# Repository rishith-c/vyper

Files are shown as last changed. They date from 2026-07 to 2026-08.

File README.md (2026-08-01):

# VYPER

A fully 3D-printed high-speed FPV quadcopter, generated from parametric CAD
and verified by an automated test suite. Inspired by the
[Peregreen V4](https://airshaper.com/cases/peregreen-v4-fastest-drone) — the
3D-printed quadcopter that set the Guinness record at 657.59 km/h.

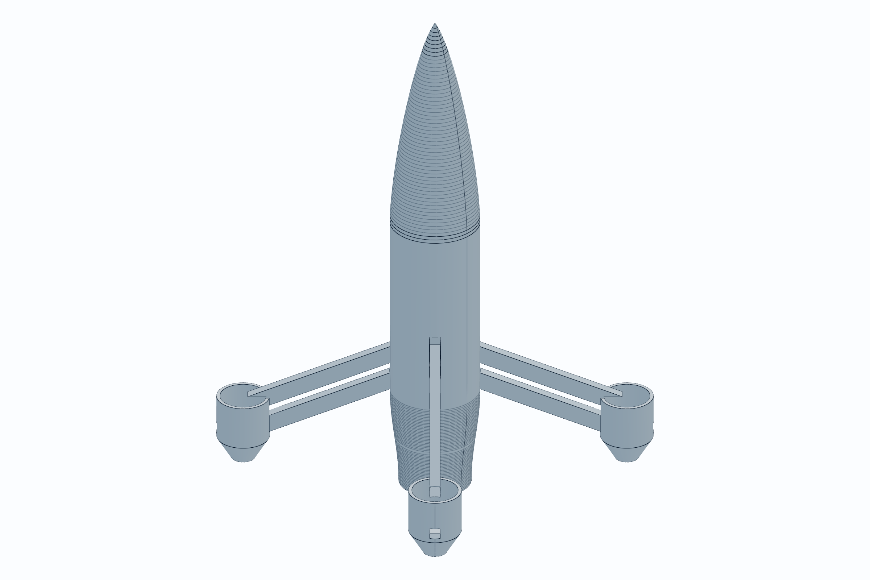
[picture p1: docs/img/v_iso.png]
assembly


| | |
|---|---|
| All-up weight | **567 g** |
| Thrust-to-weight | **8.1 : 1** |
| Drag area (CdA) | **39.4 cm²** — about half an open racer |
| Top speed | 139 km/h — **prop-pitch limited, not thrust limited** |
| Fuselage | 52 × 300 mm, fineness 5.77 |
| Bill of materials | **$142** |
| Automated checks | **30, all passing** |

---

## What's here

| | |
|---|---|
| [`vyper_shell.py`](vyper_shell.py) | The whole airframe in one CadQuery script — shell, arms, hub |
| [`test_vyper.py`](test_vyper.py) | 24 checks: fit, printing, tolerances, aero, mass |
| [`vyper_assembly.py`](vyper_assembly.py) | Assembly for review renders |
| [`firmware/`](firmware/) | Betaflight config + bench and pre-flight procedure |
| [`docs/BOM.md`](docs/BOM.md) | Every part, exact dimensions, links |
| [`pcb/`](pcb/) + [`docs/PCB_DESIGN.md`](docs/PCB_DESIGN.md) | Custom VYPER-F4 flight controller: KiCad 9 board, 15 interaction checks, dimensioned drawing |
| [`docs/TEST_REPORT.txt`](docs/TEST_REPORT.txt) | Latest full test output |
| [`stl/`](stl/) | Ready-to-print STLs |

```bash
pip install cadquery
python test_vyper.py      # verify
python vyper_shell.py     # build
```

---

## Design notes

**Von Kármán (LD-Haack) ogive nose** — the analytically minimum-drag nose for a
given length and base diameter, not a stylistic guess:

```
θ(x) = arccos(1 − 2x/L)
r(x) = (R/√π) · √(θ − sin(2θ)/2)
```

It meets the parallel body with zero slope discontinuity, so there's no
shoulder to trip the flow.

**Arms swept 22° aft, motors not canted.** On a tail-sitter the body axis *is*
the flight direction at speed, so a swept strut sees only the crossflow
component and its profile drag falls as cos²(sweep). The motor pads stay normal
to the body axis, so thrust is never canted — tilting the motors themselves
would cost 3.4 % of thrust at 15° and buy nothing here.

**Pusher, not tractor.** Motors bolt to the *aft* face of the arms with the
props behind them. A tractor gives the prop clean inflow, but its slipstream
then washes the entire fuselage above freestream velocity — and skin friction
scales with local dynamic pressure over what is nearly all the wetted area
there is. A pusher costs the prop some inflow quality and keeps the body in
clean air, which is the larger effect here. It is also why high-speed UAVs are
overwhelmingly pushers.

Consequence: motors are **inverted**, so all four directions reverse in
BLHeli/AM32 and `yaw_motors_reversed = ON`. Get that wrong and it flips on
yaw the instant you arm.

**Wire routing.** A 6 mm bore runs the length of each blade from the motor
pocket to the root, exiting inside the cavity — three 20 AWG leads (~4 mm
bundled) pull through by hand. Nothing flaps in a 139 km/h airstream. Bored
along the blade axis so it prints as a horizontal hole and bridges cleanly.

**Boat-tailed nacelles.** The pad's axis lies along the flow, so it behaves as
a nacelle and its drag is base drag off the flat aft end. Tapering to 45 %
radius removes most of that.

**Motor screws: M3×8 into a 4.0 mm pad** = 4.0 mm engagement in a 4.5 mm blind
thread. Washers under every head, because the pad is PETG and vibration embeds
a bare head over time. Threadlocker in the motor's aluminium thread, never on
the plastic.

---

## Three things the tests taught me

**Top speed was never thrust-limited.** 3.6 N of drag against 44 N available.
The ceiling is propeller pitch speed. Cutting drag doesn't raise it — it lowers
the power needed to hold it. That reframed the project: the fairing buys
efficiency and flight time, not speed.

**The tests caught what renders didn't.** A hub that exported as four
disconnected wedges. An arm frontal area computed against the wrong axis,
overstating its drag by 4.3×. A spline that self-intersected into a negative
volume. All of them looked fine on screen.

**Cheaper parts made it faster.** Re-specifying to $150 meant a smaller stack
and battery, which let the fuselage go 60 → 52 mm and lose 25 % of its frontal
area. The expensive ESC had been setting the diameter all along.

---

## Status and honesty

This is a **verified design, not a flown aircraft.** Everything here is checked
in software; none of it has been in the air. Treat the first build as a
prototype.

Known open items:
- **Motors are 84 % of remaining drag.** Fairing them is the biggest gain left.
- The fuselage is a sealed tube — there's a mandatory thermal bench check in
  [`firmware/PREFLIGHT.md`](firmware/PREFLIGHT.md) before you fly it.
- The $142 BOM covers the **aircraft only**. Radio, goggles and charger are a
  further $175–325 and you cannot fly without them.

## Safety

A 567 g aircraft at 139 km/h behind four unguarded props will cause serious
injury. Props off for all bench work. Fly only where regulations allow and
where nobody else is.

MIT licensed.

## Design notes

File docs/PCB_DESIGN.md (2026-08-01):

# VYPER-F4 — custom flight controller PCB

A placement-complete, dimensionally verified KiCad board for the VYPER
airframe. **15 automated interaction checks pass** (`pcb/test_vyper_f4.py`).

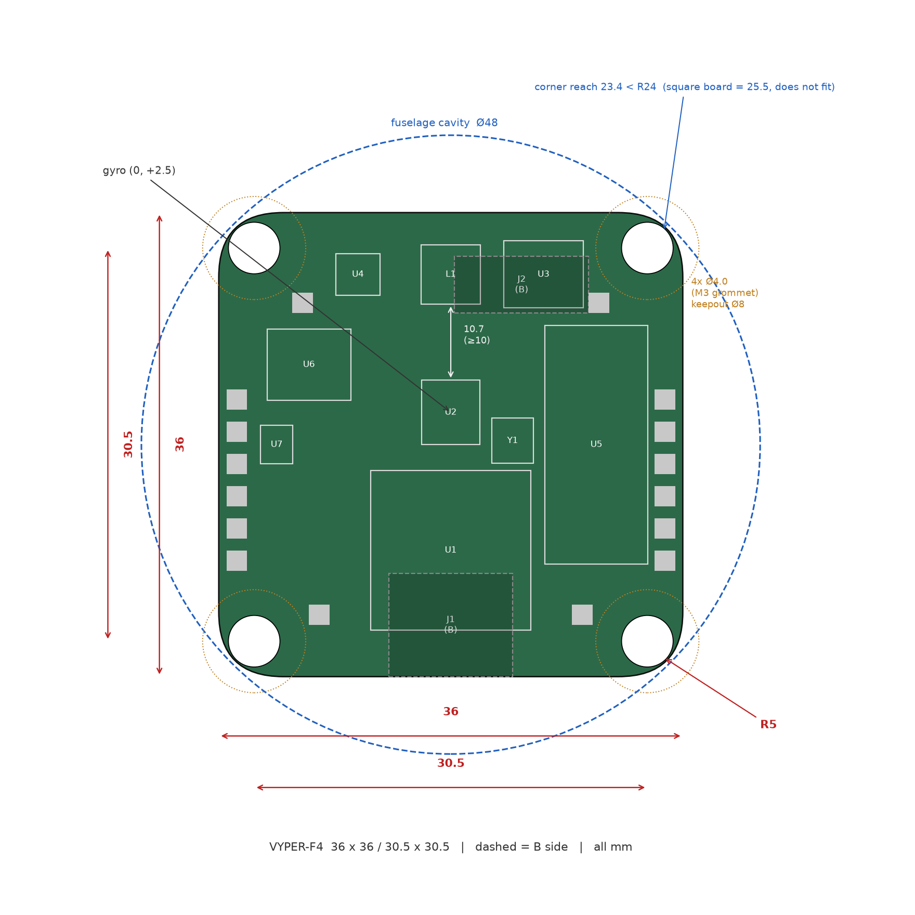
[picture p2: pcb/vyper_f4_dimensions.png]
dimensions


## What exists and what doesn't — read this first

| Done | Not done |
|---|---|
| Board outline, cut to the fuselage | Schematic capture (netlist) |
| 30.5×30.5 Φ4.0 grommet holes | Copper routing |
| Every major part placed, real package sizes | DRC against a fab profile |
| Courtyard / hole / pad interaction checks | Ordering files (gerbers/BOM/CPL) |
| KiCad 9 file that opens clean | |

That split is deliberate. Placement and dimensions are where an FC spin
dies silently — a board that doesn't fit its frame, holes that eat a
courtyard, a gyro next to an inductor. Routing is real work too, but it
fails *loudly* in DRC. Do it in the KiCad GUI or hand the placed board to an
AI router (below).

## The AI-tool landscape (researched July 2026)

| Tool | What it actually does | Use here? |
|---|---|---|
| [Quilter](https://www.quilter.ai/blog/the-2026-guide-to-autonomous-pcb-design-quilter-vs-deeppcb-vs-flux-ai) | Physics-driven cloud place-and-route of a *finished schematic*. Free tier. | **Yes** — best fit for routing this board once the netlist exists |
| [DeepPCB](https://www.protoflow.ai/compare/ai-pcb-autorouter-comparison) (InstaDeep) | RL-based cloud autorouter, free tier + pay-as-you-go | Yes, alternative router |
| [Flux.ai](https://www.protoflow.ai/compare/best-ai-pcb-design-software-2026) | Browser ECAD with AI copilot; explicitly *not* a full autorouter — route critical nets by hand, let it finish | Maybe, if you want schematic + layout in one tool |
| KiCad 9 + this repo | Deterministic generation from a Python layout file | What we did |

None of them design a *flight controller* for you: every tool above starts
from a schematic and placement intent. The intelligence in an FC layout is the
placement rules — which is exactly the part encoded and tested here.

## Design principles applied (and where each came from)

Sources: [Betaflight manufacturer design guidelines](https://betaflight.com/docs/development/manufacturer/manufacturer-design-guidelines),
[PCBSync drone PCB engineering guide](https://pcbsync.com/drone-pcb-design/),
[AllPCB flight-control layout guide](https://www.allpcb.com/allelectrohub/the-ultimate-guide-to-drone-flight-control-pcb-design-optimizing-for-performance-and-reliability).

1. **Gyro near the rotation centre, on the board axes.** ICM-42688-P at
   (0, +2.5) — 2.5 mm off centre, limit 4. A FWD axis mark is on the silk
   because a rotated gyro is a config error you chase for a week.
2. **Gyro ≥ 10 mm from anything that switches.** The buck inductor's field
   couples into the MEMS structure and reads as vibration that no filter
   fully removes. Measured on this board: **10.7 mm**, checked.
3. **Gyro-to-MCU SPI under 10 mm.** Courtyard gap here: ~0.8 mm.
4. **Soft mounting is a requirement, not a preference.** Hard-bolting the
   board flexes it and permanently shifts gyro bias — hence Φ4.0 holes for
   M3 grommets and a Φ8 keepout ring at each corner *on both faces*.
5. **Solid ground under the IMU; 4-layer stack** (sig / GND / PWR / sig)
   when routed — a continuous plane under high-frequency parts is the
   cheapest EMI fix there is.
6. **Power entry short and fat, cap at the connector.** Battery spikes on
   6S/4S kill FCs; the 470 µF low-ESR lives at the XT60, not on this board.
7. **USB and ESC socket on the bottom face** — the ESC harness plugs
   straight up from the stack below; USB faces the open tail of the
   fuselage. This is a case where the *airframe* dictated the PCB.

## Why the board is shaped by the fuselage

Two findings the checks enforce forever:

- **A square 36×36 board does not fit the VYPER fuselage.** Cavity radius is
  24 mm; a square board's half-diagonal is 25.46 mm. Corner radius ≥ 3.5 mm
  is *structural to the fit*; we use R5 → 23.38 mm reach, 0.6 mm air.
- **The classic corner motor-pad position is illegal on this board.** At
  (±13, ±13) all four pads sit inside the grommet keepouts — and M3
  additionally landed inside the blackbox-flash courtyard. The checks caught
  both; pads moved inboard.

## ESC: researched, deliberately not DIY'd

The same research pass covered ESC layout (gate-drive loops, shunt placement,
FET thermal spreading, bulk capacitance per phase). Conclusion: a 40 A 4-in-1
ESC is a **power-electronics project with a failure mode that takes the
battery with it**, on a board that costs $30 to buy with AM32 already on it.
Custom FC: sensible learning project. Custom ESC on a first spin: not.
Principles are in the sources above if you want them.

## Reproduce

```bash
cd pcb
python3 vyper_f4_gen.py                 # emit vyper_f4.kicad_pcb
python3 test_vyper_f4.py                # 15 interaction checks
../.venv/bin/python vyper_f4_drawing.py # dimensioned drawing
kicad-cli pcb render --side top --output top.png vyper_f4.kicad_pcb
```

The `.kicad_pcb` opens directly in KiCad 9 for schematic-linking and routing.

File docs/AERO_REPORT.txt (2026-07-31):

=== arms ===
two blades, 9 x 18 mm, 255 mm long, crossing at 77 deg
blade frontal silhouette      34.8 cm^2
  The blades make no useful lift and are not meant to. The whole
  point of this layout is that a 9 mm blade edge-on costs almost
  nothing, so the drag budget is body + motors and nothing else.

=== frame geometry ===
stretched X: 176 mm fore-aft / 140 mm lateral = 1.26:1
lateral spacing sits at the 127 mm prop minimum + 13 mm
exposed blade frontal area  34.8 cm^2

=== drag build-up ===
  fuselage           CdA =   3.02 cm^2  (   8 %)
  2 blades           CdA =   6.96 cm^2  (  18 %)
  4 motor bells      CdA =  28.67 cm^2  (  74 %)
  interference x1.15
  TOTAL              CdA =  44.45 cm^2
  open racer, same class   75.00 cm^2   -> 41 % less drag
  NOTE: the motors are now the single largest drag item. Fairing
  the airframe has made the bare bells the thing worth attacking.

=== top speed ===
prop 5x4.3 at ~30,303 rpm -> pitch speed  55.2 m/s
realistic max level speed       41.4 m/s =   149 km/h
drag there  4.66 N against  62.8 N available
  Thrust is NOT the limit -- prop pitch is. This is the single most
  important result here: the fairing does not raise the ceiling,
  it lowers what it costs to sit at the ceiling.

=== what the fairing actually buys ===
  at 30 m/s (108 km/h): drag 2.45 N vs 4.13 N open  ->  41 % less power to hold speed
  at 40 m/s (144 km/h): drag 4.36 N vs 7.35 N open  ->  41 % less power to hold speed

=== hover ===
disc area (4 props)           507 cm^2
disc loading                118.6 N/m^2
induced velocity              7.0 m/s
ideal hover power              42 W  (x ~1.9 for real figure of merit -> 79 W)
blade area inside the discs    42 cm^2 =  8.2 % of disc area  (measured)
estimated hover download    0.5 % of thrust  =   31 g
  Two thin blades block far less of the disc than the wing panels
  did, which is the other half of why this layout is better here.

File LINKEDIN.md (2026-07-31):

# VYPER — LinkedIn project write-up

> Paste into the *Projects* section, or post as-is. Trim to taste.

---

**VYPER — a fully 3D-printed high-speed FPV drone, designed parametrically and verified by test**

I built a complete rocket-style FPV quadcopter airframe in code — every part
generated from a parametric CAD script, and every design claim checked by an
automated test suite rather than by eye.

**The idea.** Inspired by the Peregreen V4, the fully 3D-printed quadcopter
that took the Guinness record at 657.59 km/h. I wanted to understand what
actually makes an airframe fast, on a $142 budget and a consumer printer.

**What I built**
• A parametric CadQuery model of the full airframe: Von Kármán minimum-drag
  ogive nose, 2 mm hollow fuselage, four swept blade arms, boat-tailed motor
  nacelles, internal flight-stack shelf.
• A 24-check automated test suite covering fit, printability, tolerances,
  aerodynamics and mass — run on every change.
• A component drag build-up, prop-pitch speed model, and full mass budget.
• Betaflight firmware configuration with every non-default value justified.

**Results**
• 567 g all-up, 8.1:1 thrust-to-weight
• CdA 39.4 cm² — roughly half a conventional open racer
• Fuselage fineness ratio 5.77, inside the low-drag optimum band
• $142 bill of materials

**What I actually learned — the useful part**

*Top speed was never limited by thrust.* The model showed 3.6 N of drag against
44 N of available thrust. The real ceiling is propeller pitch speed. Halving
drag doesn't raise the ceiling — it lowers the power needed to sit at it. That
reframed the whole project: the fairing buys efficiency and flight time, not
top speed.

*The tests caught what my eyes didn't.* An internal hub exported as four
disconnected wedges. An arm's frontal area computed against the wrong axis,
overstating its drag by 4.3×. A camera bay placed where the nose taper couldn't
hold it. A spline that self-intersected and produced a negative volume. Every
one of those looked fine in a render.

*Cheaper parts made the aircraft faster.* Re-specifying to a $150 budget meant a
smaller flight controller and battery — which let the fuselage shrink from 60 mm
to 52 mm and lose 25 % of its frontal area. The expensive component had been
setting the diameter all along.

**Stack:** Python, CadQuery, build123d, OpenCascade, Betaflight

Repo: github.com/rishith-c/vyper

#Engineering #Aerospace #CAD #3DPrinting #Python #FPV #Drones #Aerodynamics

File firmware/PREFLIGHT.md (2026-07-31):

# VYPER — bench and pre-flight procedure

**Props off for every step except the last.**

## Bench (first power-up)

1. **Smoke test on a current-limited supply if you have one.** A miswired
   4-in-1 draws hundreds of amps and destroys itself in under a second.
2. Flash Betaflight, then paste `betaflight_vyper.txt` in the CLI, `save`.
3. **Motors tab** — verify direction and order. Fix rotation in BLHeli/AM32,
   not by swapping wires.
4. **Receiver tab** — all channels move the right way, endpoints 1000–2000.
5. **Failsafe** — power the radio off with motors spinning (props off). Motors
   must stop within 4 s. If they don't, stop and fix it.
6. **Accelerometer calibration** on a level surface.
7. **VTX** — 25 mW indoors, and never power it without an antenna.

## The one that is specific to this airframe

8. **Thermal check.** Spool to 50 % for 30 s **with the canopy closed**, then
   immediately feel the ESC. This is a sealed 300 mm tube; the cooling path
   runs nose inlet → cavity → tail. If the ESC is too hot to hold, open the
   inlet before you fly. A closed fuselage is the real risk here, not thrust.

## First flight

9. Props on last. Check each direction against the Betaflight diagram.
10. Hover 1 m for 30 s. Land. **Feel every motor.** Anything hot means a
    prop/tune/bearing problem — do not fly it fast.
11. Only then open it up.

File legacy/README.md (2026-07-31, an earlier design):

# Legacy — earlier design iterations

This project went through several airframe layouts before the current one.
They are kept because the reasoning is in the commit history and some of it is
reusable, but **none of it is part of VYPER**.

- `cad_build123d/` — a build123d parametric airframe (flat-plate racer, then a
  faired fuselage with pylons, then swept wing panels, then crossed blades).
  Its own 41-check verification suite lives in that history.
- `tolerance_coupon.stl` (in `../stl/`) is still worth printing: M3/M2 hole
  ladders, wall ladder, bridge tests and an overhang fan for calibrating your
  printer before committing to a long part.

The current design is the CadQuery model at the repo root.

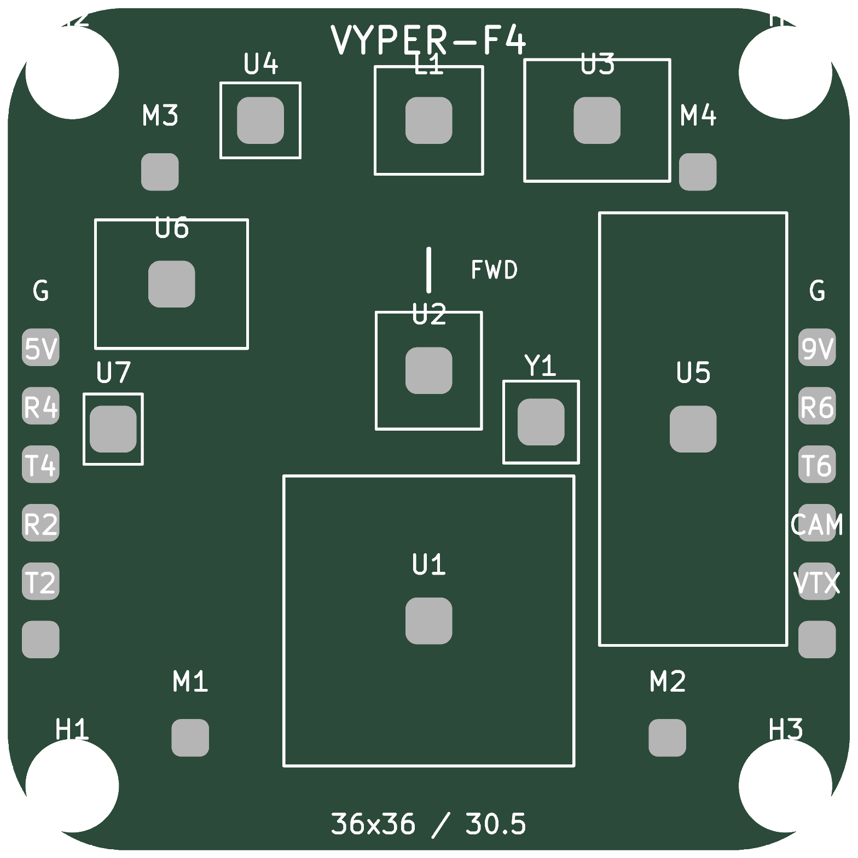
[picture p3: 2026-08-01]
docs/img/vyper_f4_top.png

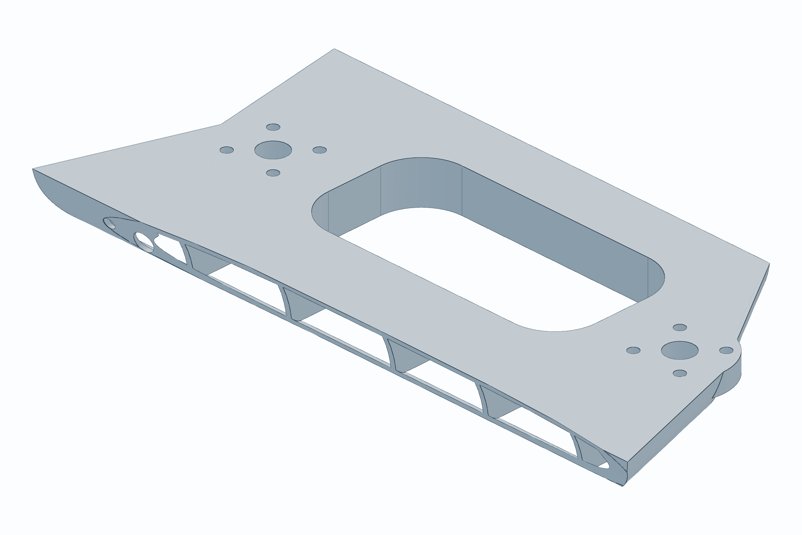
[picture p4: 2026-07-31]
docs/img/part_wing.png

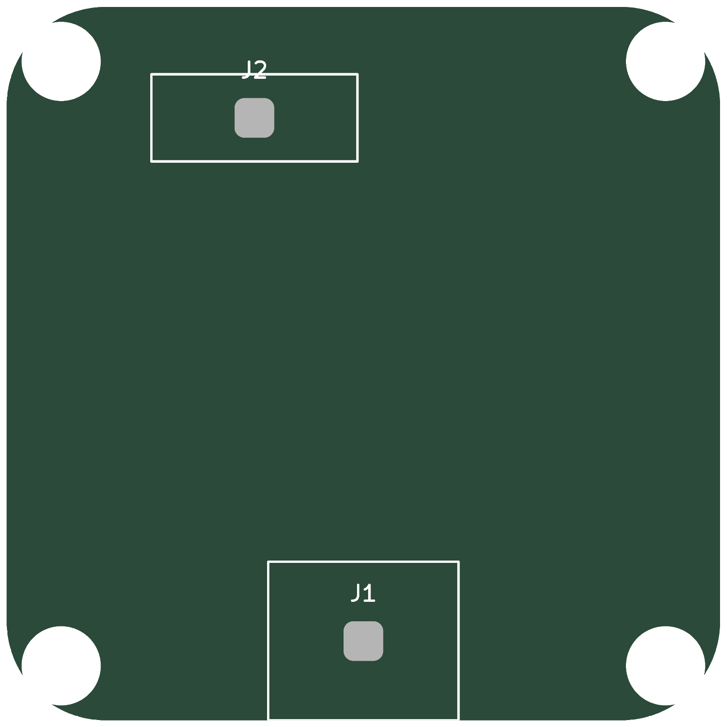
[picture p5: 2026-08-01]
docs/img/vyper_f4_bottom.png

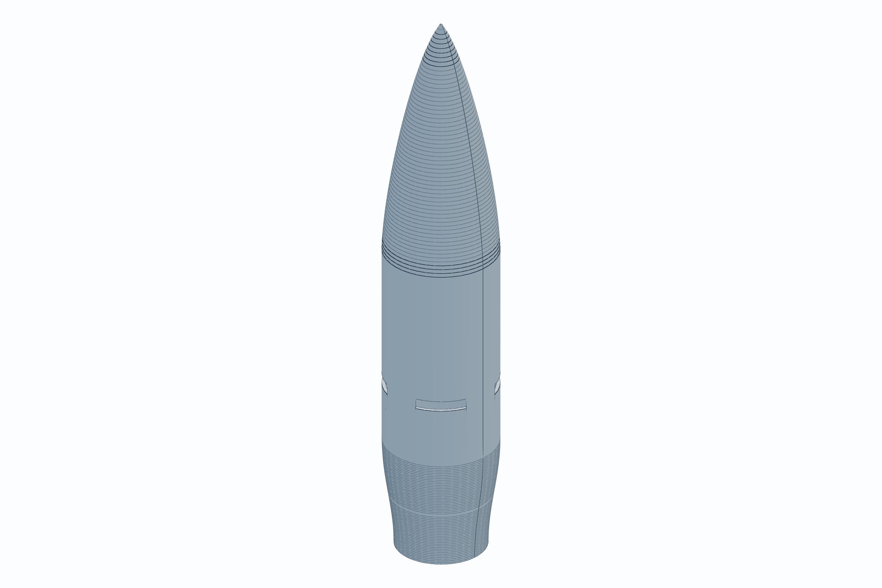
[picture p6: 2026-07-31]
docs/img/peregreen.png

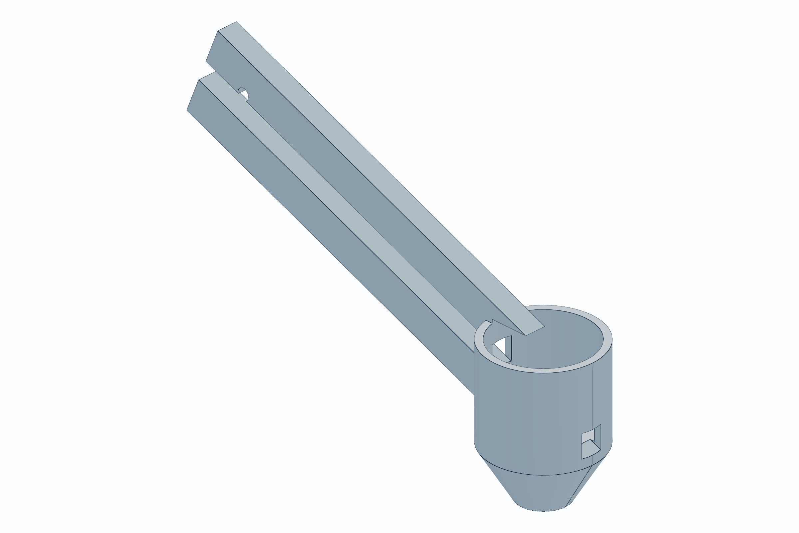
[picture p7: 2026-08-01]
docs/img/v_arm.png

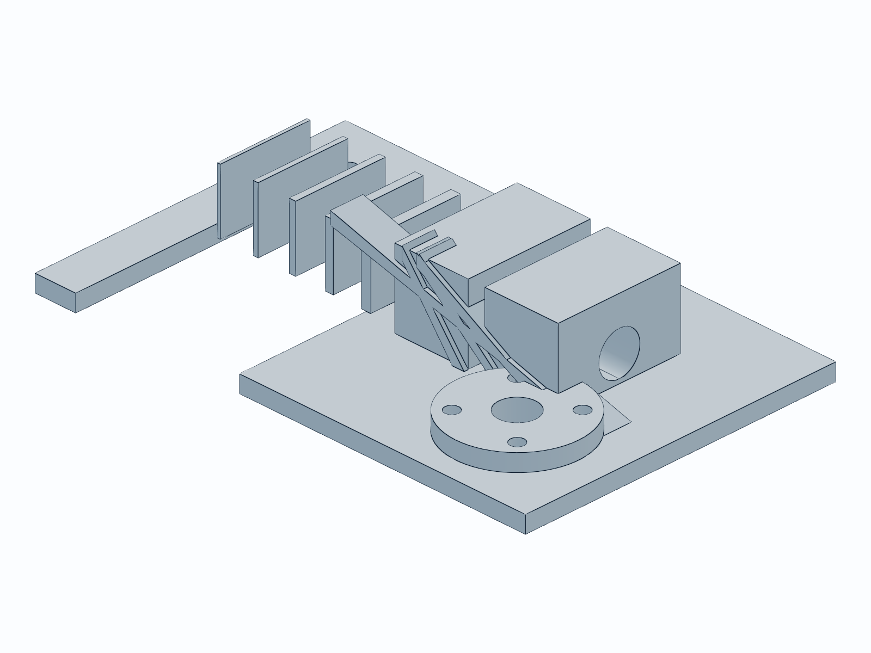
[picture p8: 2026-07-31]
docs/img/part_coupon.png

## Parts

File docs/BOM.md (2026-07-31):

# VYPER — Bill of Materials, under $150

Every line carries the **exact dimensions the CAD is cut to**. Substituting a
part with different dimensions means editing the parameter named in the last
column and re-running the script.

Links are **search pages, not single listings** — deliberately. AliExpress
listings churn weekly and a dead link is worse than no link; a search that
still resolves in six months is more useful. Filter by the dimensions in the
table, which are what the CAD is actually cut to.

Prices are typical AliExpress street, July 2026. AliExpress hides item pages
behind a login wall so I could not verify them line by line — treat them as a
budget, not a quote, and check before ordering.

## Section A — the aircraft

| # | Part | **Exact dimensions** | Mass | $ | CAD parameter |
|---|---|---|---|---|---|
| 1 | [2207 motor ×4, **2450KV** (4S)](https://www.aliexpress.com/w/wholesale-2207-2450kv-motor.html) | Ø27.9 × 32.4 mm; **16×16 mm M3** bolt square; M5 shaft; **4.5 mm blind thread depth** (2207s ship for 4–5 mm arms) | 32 g ea | 44 | `MOTOR_PATTERN = 16.0` |
| 2 | [F405 FC + 40A 4in1 ESC stack](https://www.aliexpress.com/w/wholesale-f405-40a-4in1-stack-30.5.html) | ESC **36.0 × 36.0 × 7.5 mm**; FC 36.0 × 36.0 × 6.5 mm; **30.5 × 30.5 M3**; 15 mm stacked | 22 g | 30 | `STACK_PITCH = 30.5` |
| 3 | [4S 1500 mAh LiPo, XT60](https://www.aliexpress.com/w/wholesale-4s-1500mah-lipo-xt60.html) | **75 × 35 × 30 mm** | 165 g | 16 | `R_MAX` (see note) |
| 4 | [Micro FPV camera, 19 mm](https://www.aliexpress.com/w/wholesale-19mm-micro-fpv-camera.html) | **19.0 × 19.0 × 21 mm** body; M2 side pivot, 19 mm across ears | 8 g | 11 | — |
| 5 | [5.8 GHz VTX, 25–400 mW](https://www.aliexpress.com/w/wholesale-5.8g-vtx-400mw-mmcx.html) | **26 × 26 × 6 mm**; MMCX | 8 g | 10 | — |
| 6 | [ExpressLRS 2.4 GHz nano RX](https://www.aliexpress.com/w/wholesale-expresslrs-2.4ghz-nano-receiver.html) | **15 × 11 × 4 mm** | 1.5 g | 8 | — |
| 7 | [5×4.3×3 props, 2 sets (8)](https://www.aliexpress.com/w/wholesale-5x4.3x3-propeller.html) | **127 mm** dia; 5.0 mm bore | 4.5 g ea | 5 | `PROP_DIA` |
| 8 | [M3 hardware assortment](https://www.amazon.com/s?k=m3+socket+cap+screw+assortment+stainless) | — | 40 g | 12 | — |
| 9 | [PETG filament, ~250 g](https://www.amazon.com/s?k=petg+filament+1.75mm) | 1.75 mm | — | 6 | — |
| | | | | **$142** | |

**Why 4S, not 6S.** It is the single cleanest $10 saving, and the 4S pack is
*smaller* — which is the interesting part. See the note below.

## The budget change made the airframe faster

The $200 build was sized around a SpeedyBee ESC at **45.6 × 44 mm** and a 6S
1050 at 76 × 38 × 31 mm. That 44 mm ESC forced a 60 mm body.

The budget stack is **36 × 36 mm** and the 4S 1500 is **75 × 35 × 30 mm**:

```
battery half-diagonal = sqrt(17.5^2 + 15.0^2) = 23.0 mm
required internal radius                      = 23.0 + 1.0 fit = 24.0 mm
required outer radius                         = 24.0 + 2.0 wall = 26.0 mm
```

So `R_MAX` drops **30 → 26 mm**, a **52 mm body instead of 60 mm**. Frontal
area falls from 28.3 to 21.2 cm², **25 % less**. Cheaper parts, slimmer
aircraft — the constraint that set the diameter was the expensive ESC.

## Section B — hardware (line 8)

| Item | Size | Qty | Where |
|---|---|---|---|
| M3 × 8 socket cap | ISO 4762, Ø5.5 head | 16 | Motors. 4.0 mm pad → **4.0 mm engagement** in a 4.5 mm blind hole |
| M3 washer, Ø7 × 0.5 | | 16 | **Under every motor screw** — see note |
| M3 × 20 socket cap | | 4 | Arm root → internal hub |
| M3 × 8 button head | | 4 | Stack → shelf, 30.5 × 30.5 |
| M3 washer | Ø7 × 0.5 | 8 | Frame bolts |
| M2 × 8 | | 2 | Camera pivot |
| XT60 pigtail | 14 AWG, 100 mm | 1 | |
| Capacitor | **470 µF / 35 V**, Ø10 × 20 mm low-ESR | 1 | Across XT60. Not optional |
| Heatshrink / zip ties | | | |

## Motor screws — the numbers

```
pad thickness            4.0 mm
screw M3 x 8             8.0 mm
engagement = 8.0 - 4.0 = 4.0 mm   into a 4.5 mm blind thread
remaining clearance      0.5 mm    -> does NOT bottom out
```

**I previously told you the thread depth was 3.0 mm and to consider M3×6.
That was wrong.** 2207-class motors are built for 4–5 mm carbon arms and ship
M3×8 for exactly this stack-up; their blind holes are 4.5–5 mm. A 4.0 mm pad
with M3×8 is the standard, correct combination. M3×6 would leave only 2 mm of
engagement and is the worse choice.

**Still measure yours before the first build.** Run an M3×8 into a bare motor
by hand: it should turn freely to ~4 mm and stop against thread, not jam. If
it jams early the hole is shallower than spec and you drop to M3×6.

Two things that *are* worth doing, because the pad is PETG and not carbon:

* **Washer under every motor screw.** An M3 socket head is Ø5.5 mm, giving
  15.7 mm² of bearing. At max thrust each screw sees ~4.8 N → 0.3 MPa, which
  is nothing — but vibration cycling a bare head against plastic will slowly
  embed it. A Ø7 washer nearly doubles the seat area for 0.1 g.
* **Blue threadlocker in the motor threads, not the plastic.** The thread is
  aluminium; that is where the locking happens. Never put threadlocker on the
  printed pad.

The screw head seats on a **flat, machined-square pocket ceiling** — the pad
is hollowed from below, so the head bears on a true flat, not on a curved
nacelle surface. There is 2.4 mm of material outboard of each hole.

## NOT included — you cannot fly without these

| Item | $ |
|---|---|
| ELRS radio (RadioMaster Pocket) | 65–95 |
| Analog FPV goggles | 70–160 |
| 4S-capable balance charger | 30–60 |
| LiPo safe bag | 10 |
| | **$175–325** |

If you already own these, $142 is the whole aircraft. If not, the real
first-time cost is **$317–467** and no BOM can change that.

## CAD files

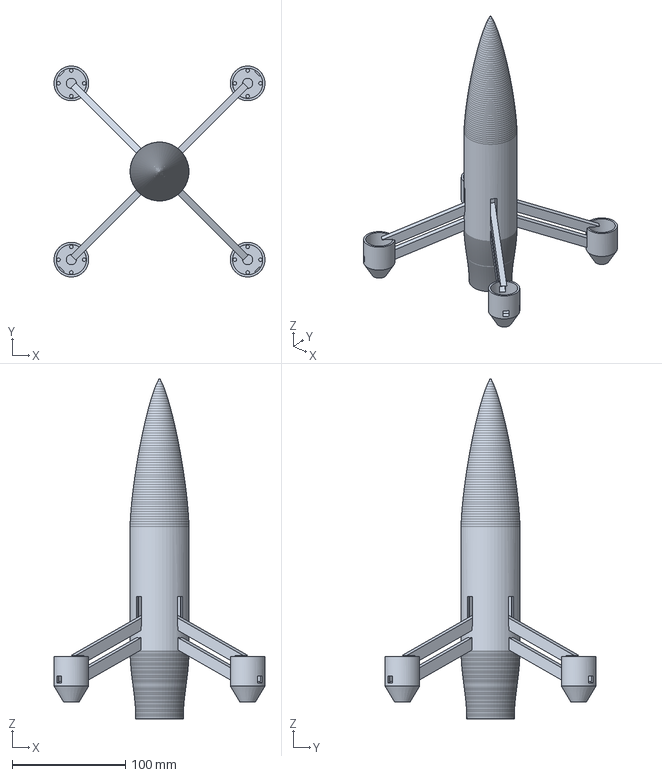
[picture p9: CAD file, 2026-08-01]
cad/vyper_assembly.step
186.2 x 186.2 x 300.0 mm

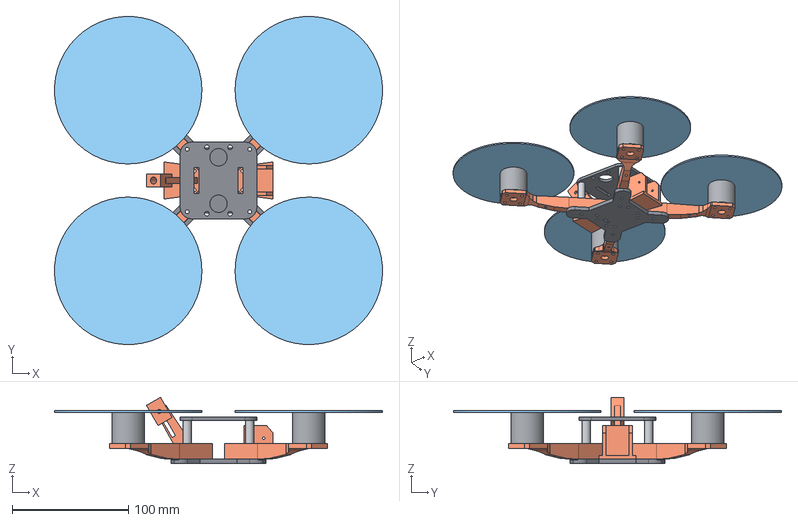
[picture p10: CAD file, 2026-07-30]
cad/assembly.step
282.4 x 282.4 x 57.2 mm
bottom_plate
arm_4 x 4
standoff_4 x 4
top_plate
camera_cage
antenna_mount
REF_motor_1
REF_propdisc_1
REF_motor_2
REF_propdisc_2
REF_motor_3
REF_propdisc_3
REF_motor_4
REF_propdisc_4

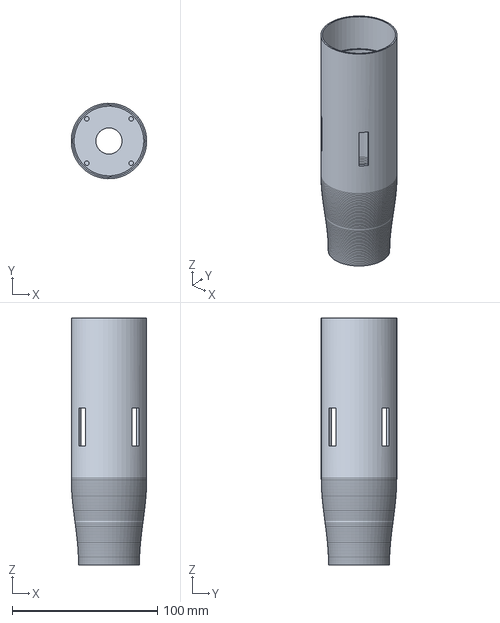
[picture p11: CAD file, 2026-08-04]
cad/vyper_shell_body.step
52.0 x 52.0 x 170.0 mm

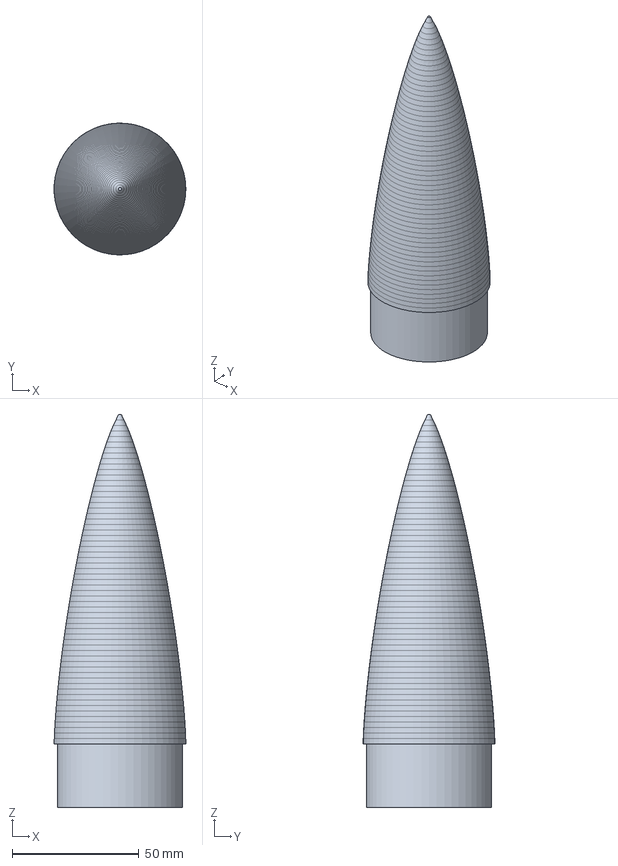
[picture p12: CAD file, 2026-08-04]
cad/vyper_shell_nose.step
52.0 x 52.0 x 155.0 mm

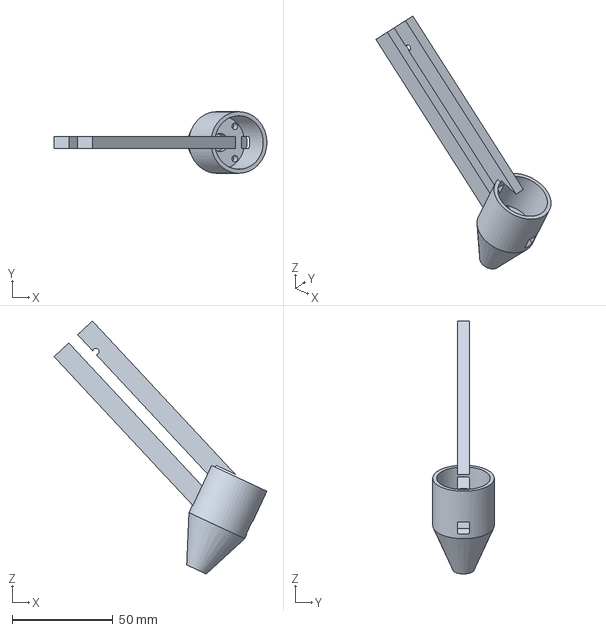
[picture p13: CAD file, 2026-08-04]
cad/vyper_arm_print.step
105.7 x 30.6 x 125.7 mm

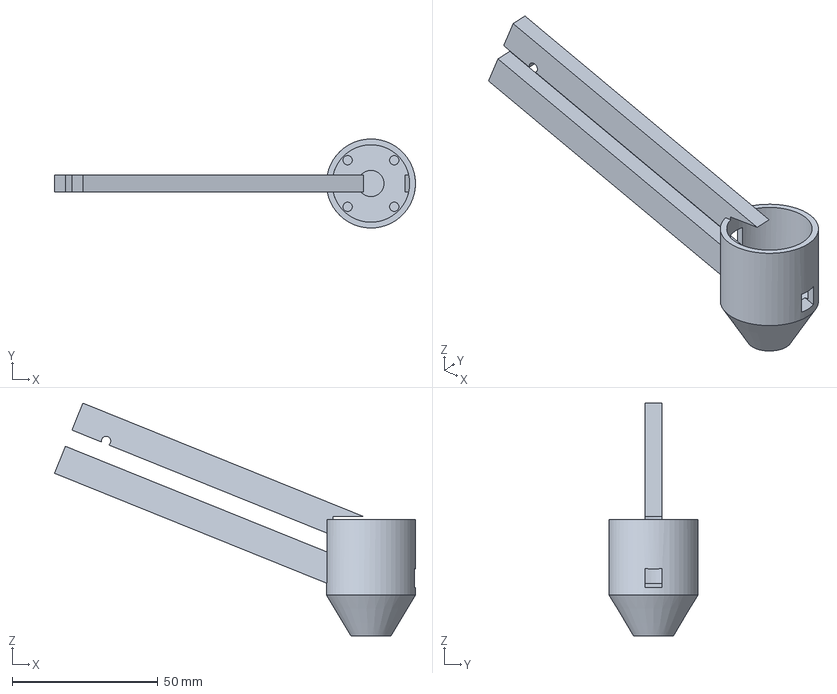
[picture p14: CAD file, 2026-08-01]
cad/vyper_arm.step
124.1 x 30.6 x 80.0 mm

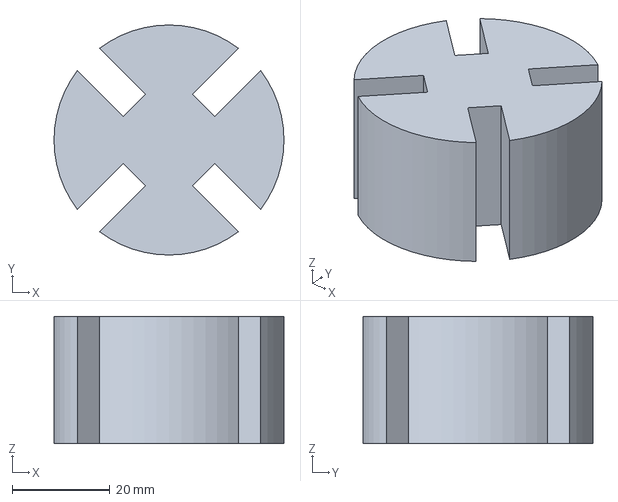
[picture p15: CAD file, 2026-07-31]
cad/vyper_hub.step
47.0 x 47.0 x 26.0 mm

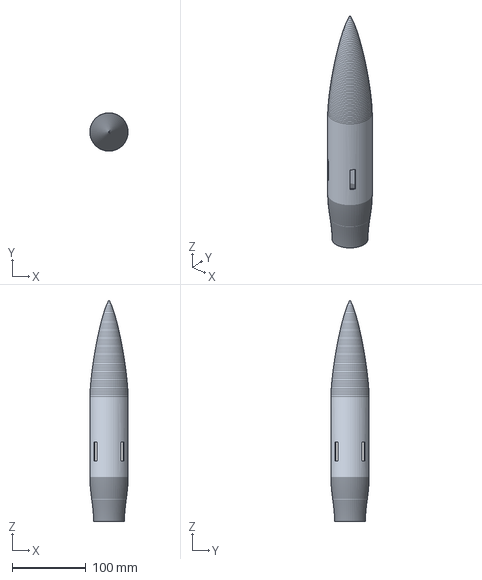
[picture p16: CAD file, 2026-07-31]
cad/vyper_shell.step
52.0 x 52.0 x 300.0 mm

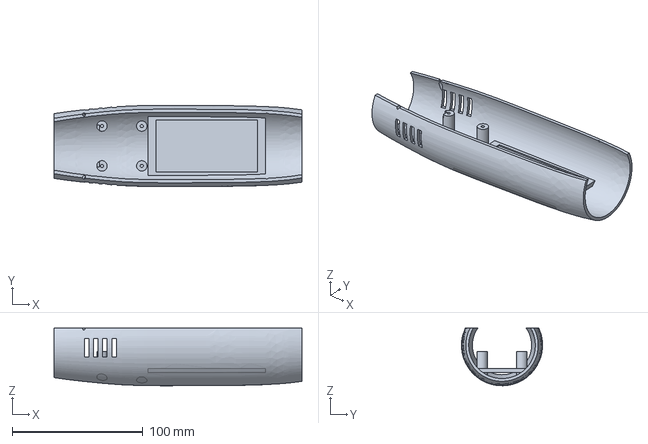
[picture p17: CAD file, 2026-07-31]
cad/fuselage_lower.step
190.0 x 62.2 x 44.1 mm

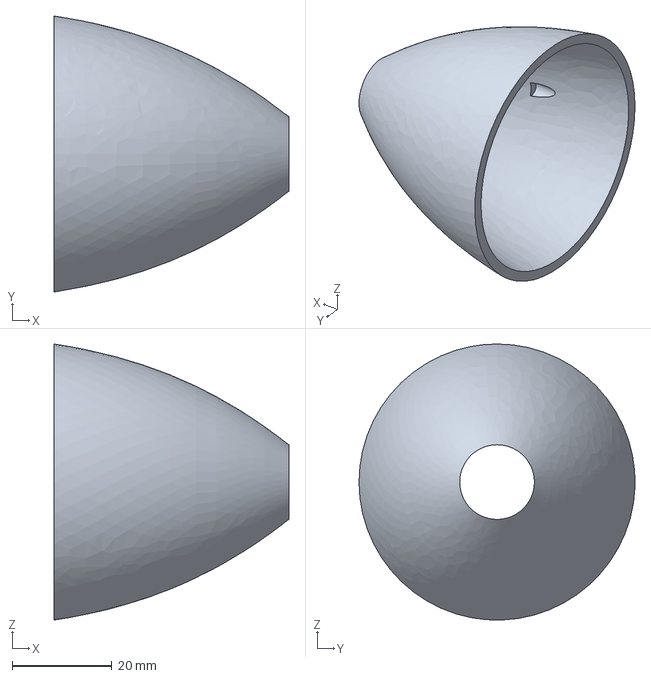
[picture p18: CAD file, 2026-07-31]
cad/nose_cone.step
47.1 x 55.5 x 55.5 mm

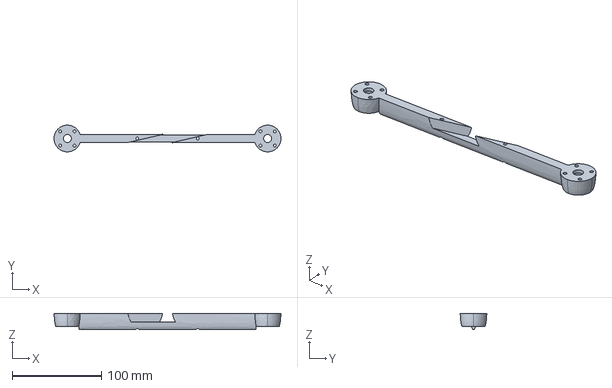
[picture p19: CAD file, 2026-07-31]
cad/arm_top.step
254.9 x 30.0 x 18.0 mm

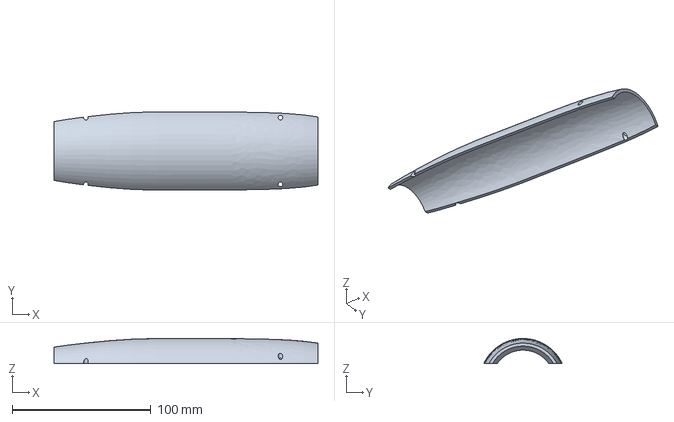
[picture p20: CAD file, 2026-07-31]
cad/fuselage_upper.step
190.0 x 56.4 x 18.0 mm

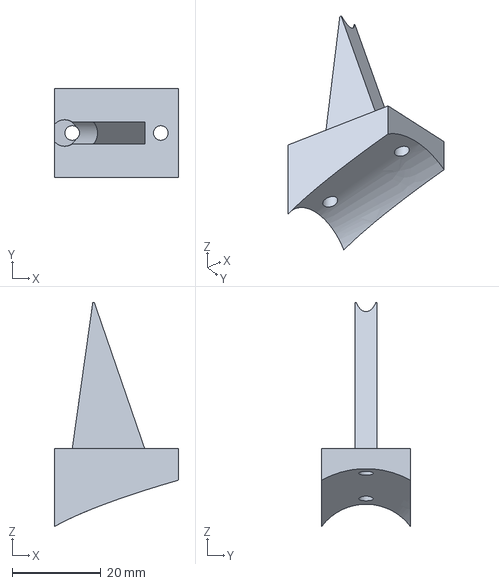
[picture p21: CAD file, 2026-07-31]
cad/tail_fin.step
28.0 x 20.0 x 50.6 mm

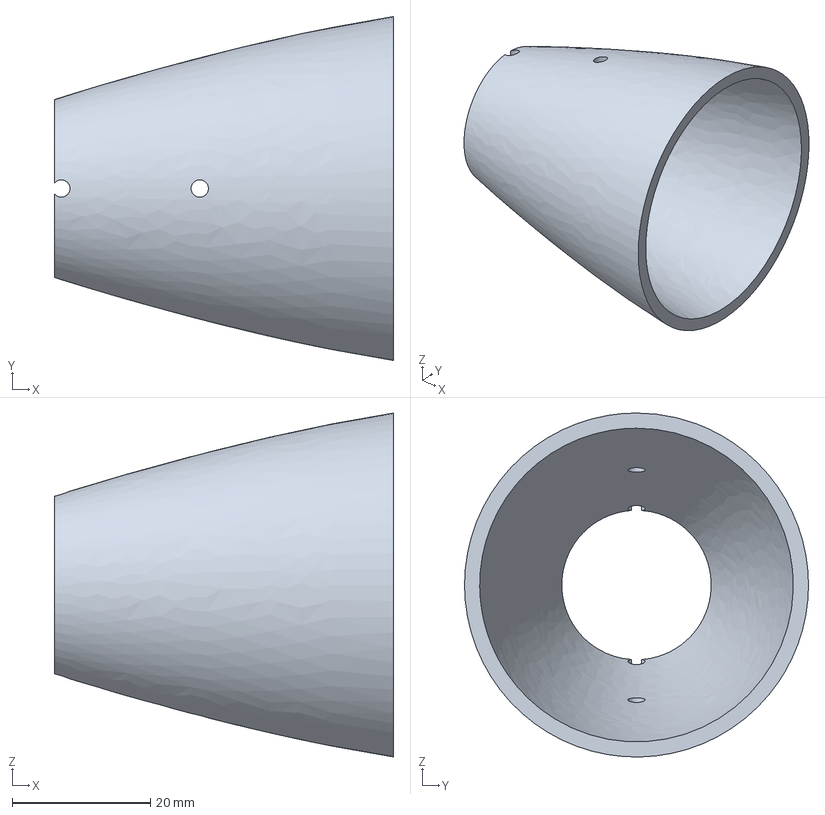
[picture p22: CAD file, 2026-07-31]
cad/tail_cone.step
49.0 x 49.7 x 49.7 mm

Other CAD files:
cad/pg_assembly.step
cad/arm_bottom.step
cad/tolerance_coupon.step
legacy/cad_build123d/assembly.step
legacy/cad_build123d/arm_bottom.step
legacy/cad_build123d/assembly_view.step
legacy/cad_build123d/pg_assembly.step
legacy/cad_build123d/tolerance_coupon.step
stl/tolerance_coupon.stl
stl/vyper_arm.stl
stl/vyper_arm_print.stl
stl/vyper_hub.stl
stl/vyper_shell_body.stl
stl/vyper_shell_nose.stl

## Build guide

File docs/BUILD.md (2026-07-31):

# VYPER-5X — Printing and Assembly

## Part 1: Printing

### Settings (Elegoo Neptune 4, 0.4 mm nozzle, PETG)

| | |
|---|---|
| Layer height | 0.20 mm |
| **Walls / perimeters** | **5** — this is the important one |
| Top / bottom layers | 5 |
| Infill | 20% gyroid (shells), 15% gyroid (pylons) |
| Nozzle | 240 °C |
| Bed | 80 °C |
| Cooling | 40-50% |
| Speed | ≤ 60 mm/s on walls |
| Supports | **None. Not on any part.** |
| Brim | None needed |

**Why 5 walls matters more than infill.** Almost every part here is a shell.
The walls *are* the structure and infill is close to irrelevant — the pylon
strut only sees about 1.8 MPa against ~45 MPa PETG yield, because a fairing
gets a deep section for free. Going from 3 walls to 5 is most of the strength;
going from 20 % to 60 % infill just adds mass.

Slow the walls down. Peak stress is carried by the outer perimeters running the
length of the pylon; a wall laid down at 100 mm/s bonds worse than one at 50.

### Orientation — the part that actually matters

| Part | Orientation | Why |
|---|---|---|
| **Arm ×2** | **Flat top DOWN, rotated 45° on the bed** | 255 mm will not fit a 225 mm bed square. See below. |
| Fuselage lower | Cut face down (as exported) | Half-tube, section shrinks upward |
| Fuselage upper | Cut face down (as exported) | Same |
| Nose cone | Open end down (as exported) | A dome; shrinks all the way to the tip |
| Tail cone | Open end down (as exported) | Same |
| Tail fin | Flat on its side (as exported) | Loads are in-plane |

**The arms must be rotated on the bed.** They are 255 × 30 mm; rotated 45° they
need (255+30)/√2 = 201 mm in both axes, so they fit a 225 mm bed with 24 mm to
spare. There is no rotation angle at which they fit unrotated — 255 > 225 in one
axis no matter what.

Every STL is already oriented correctly. **Drop them in the slicer and do not
rotate anything.**

#### If you take one thing from this document

The arm's flat top is the motor mounting surface, and it goes **on the bed**.

- The arm's belly rounds away on the *other* side, so the cross-section only shrinks
  going upward. No overhangs, no supports, nothing to clean up.
- Bed contact is a 255 × 9 mm strip plus two 30 mm pads. Use a brim.
- The bending fibres end up as continuous perimeters running the full length.
- Layer adhesion only sees transverse shear (~0.6 MPa against a bond good for
  25+ MPa).

Print an arm on its side or on its end and it will snap at the root on the
first hard landing, because you will have put the layer boundaries square
across the tension face. It also puts a 77 degree overhang along the whole
upper surface.

### Print order

Print the **tolerance coupon** first (20 min, 39 g), then **one arm**. Check the
half-lap notch is 9.0 mm deep, the flat top sits on glass with no rock, and the
pad under each motor measures 4.0 mm. Then print the rest.

Total print time is roughly 18-24 hours for the full set. About 190 g of
filament, so budget 350 g including one failure.

### Post-print

- The **wire tunnel** through each pylon and the **M2 camera holes** are the
  only horizontal bores; they bridge with slight droop. Run a drill through by
  hand before assembly.
- Test-fit an M3 through the pylon flange holes. If tight, run a 3.3 mm drill
  rather than forcing the bolt — forcing it splits the layers.
- Deburr the motor pads so the motors seat flat.
- Dry-fit the pylon saddles against the fuselage before you bolt anything. They
  are cut from the mould line with 0.6 mm of clearance, so they should drop on
  without persuasion.

---

## Part 2: Assembly

### Layout, for reference

```
  X = +112 .. +68   nose cone (removable) -- camera + cooling inlet
  X = +68 .. -92    main body: lower shell (structure) + canopy
  X = -92 .. -142   tail cone -- cooling exit; fin bolts on top
  X = +60 .. -16    battery bay, floor at Z = -18, canopy closes at Z = +13
  X = -39           stack, on four posts at 30.5 x 30.5
  Z = +16           pylon roots on the shoulder, and the motor pad plane
  Z = +42           prop plane
```

### Order

**1. Interlock the arms.**
`arm_top` is notched from the top, `arm_bottom` from the bottom. They slide
together into a flat X — 9 mm of depth each, so the assembled crossing is the
same 18 mm as the rest of the blade. If they will not seat, check the notch
depth against the coupon rather than forcing them.

**2. Arms to the fuselage spine.**
Four M3 down through the crossing into the shell, two per arm either side of
the centre. Washer under every head.

**3. Motors.**
Four **M3x8** each, up through the 4 mm pad into the bell. **Nothing longer** —
the belly pocket exists so an M3x8 is exactly right. Route the phase wires
along the blade underside into the body.

**4. Stack, VTX, RX.**
Stack on the four printed posts at 30.5 × 30.5. Solder motors, then the XT60,
then the **470 µF capacitor across the XT60 pads** — not optional on 6S.

**5. Nose cone and camera.**
Camera into its socket, one M2 per side sets tilt by friction. Two M3 hold the
nose on. Leave slack in the camera lead so the nose comes off without
unplugging.

**6. Tail cone and fin, then battery and canopy.**
Pack drops into the bay; **the canopy is the retainer**, there is no strap.

### Before the first flight

**Props off for all of this.**

1. Flash/verify Betaflight; set motor order and directions in the Motors tab.
2. Bind the RX. Confirm failsafe actually cuts the motors.
3. Check the FC arrow really is forward.
4. Set VTX band and power. **25 mW indoors**, and never power a VTX without an
   antenna.
5. Set a **3.5 V/cell** low-voltage warning.
6. **Run a 30-second bench spool-up with the canopy ON and feel the ESC after.**
   This airframe is a closed tube; if the cooling path is blocked the ESC will
   thermal-throttle and you want to find that out on the bench.
7. Props on last, checking each direction against the Betaflight diagram.

### Expect to break things

The **nose cone, tail cone and fin** are the fuses — they are on two bolts each
and are meant to come off rather than lever the shell. 7-15 g of filament each.
Print spares of all three with the first batch, plus a spare arm of each notch.

The expensive part to lose is the **lower shell** at 68 g and several hours. It
is the one part worth protecting, which is the real cost of a faired airframe
— though at 21 g an arm is cheap to replace, which is the advantage of
this layout over the wing panels.

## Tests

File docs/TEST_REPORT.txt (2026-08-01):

=== geometry / fit ===
[PASS] shell is one closed solid: 1 solid(s), 80860 mm^3
[PASS] arm is one closed solid: 1 solid(s), 23589 mm^3
[PASS] hub is one closed solid: 1 solid(s), 36171 mm^3
[PASS] 4S 1500 pack fits cavity: needs 23.0 mm internal radius, has 24.0
[PASS] 36 mm stack fits shelf: shelf clear dia 48.0 mm vs 36 mm board
[PASS] arm passes its slot: 0.4 mm total slip fit on a 6.0x26.0 blade

=== wire routing ===
[PASS] motor leads fit the arm bore: 6.0 mm bore for a ~4.0 mm bundle of 3x2.3 mm
[PASS] bore bridges without support: 6.0 mm horizontal bore -- bridges cleanly at this size
[PASS] bore leaves blade material: 20 mm of blade depth remains around it
[PASS] leads exit inside the fuselage: root at r=11.0 is inside the r=24.0 cavity

=== pusher configuration ===
[PASS] motors mounted aft (pusher): props behind the arms; fuselage stays out of the slipstream
[PASS] thrust still on the flight axis: pad is normal to the body axis -- sweep moves the arm, not the thrust

=== printing ===
[PASS] shell fits Neptune 4: 52 x 52 x 300 mm  [rotate on bed]
[PASS] arm fits Neptune 4: 124 x 31 x 80 mm
[PASS] hub fits Neptune 4: 47 x 47 x 26 mm
[PASS] wall printable at 0.4 nozzle: 2.0 mm = 5 extrusions
[PASS] motor screw engagement: M3x8 through a 4.0 mm pad = 4.0 mm into a 4.5 mm blind thread (0.5 mm spare, does not bottom out)
[PASS] screw head bearing on PETG: 0.18 MPa on 15.7 mm^2 -- use washers anyway, vibration embeds a bare head over time
[PASS] material outboard of motor holes: 2.4 mm of pad beyond each hole
[PASS] nose self-supporting: 11.3 deg from vertical at the ogive base

=== tolerances ===
[PASS] M3 motor clearance: 3.2 mm hole on 3.0 mm bolt = 0.20 mm
[PASS] M3 hub clearance: 3.2 mm hole on 3.0 mm bolt = 0.20 mm
[PASS] M3 stack clearance: 3.2 mm hole on 3.0 mm bolt = 0.20 mm
[PASS] arm slot fit: 0.4 mm -- slide fit, no hammer

=== aerodynamics ===
  body frontal    21.24 cm^2   CdA  1.91
  4 blades        20.16 cm^2   CdA  3.47   (swept 22 deg, cos^2 = 0.86)
  4 motor bells   36.16 cm^2   CdA 28.93
  TOTAL CdA       39.45 cm^2  (open racer ~75)
[PASS] drag beats an open racer: 39.4 vs 75 cm^2
[PASS] motors dominate remaining drag: 84 % -- fair them next
[PASS] thrust stays on the flight axis: pad is normal to the body axis; sweeping the arm costs no thrust
  2450KV on 4S -> ~28,283 rpm, pitch speed 51.5 m/s
  realistic top speed 38.6 m/s = 139 km/h
[PASS] prop-pitch limited, not thrust limited: 3.6 N drag at Vmax against ~44 N of 4S thrust
[PASS] fuselage fineness in the low-drag band: 5.77 (optimum ~5-6)

=== mass ===
  printed 190 g + payload 390 g = AUW 580 g
[PASS] thrust-to-weight: 7.9:1

all checks passed

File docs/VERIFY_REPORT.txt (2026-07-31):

=== airframe geometry ===
[PASS] min prop tip gap: 13.0 mm between the closest pair of discs
[PASS] stretched-X geometry: 176 mm fore-aft / 140 mm lateral = 1.26:1
[PASS] lateral spacing at prop minimum: 13 mm tip gap -- narrow is the point
[PASS] motor tilt shipped: 0 deg -- conventional; see vy_params docstring

=== bought parts vs printed parts ===
[PASS] battery clash: 0.0 mm^3 into printed material
[PASS] battery inside cavity: 0.0 mm^3 of 89528 outside the fuselage
[PASS] stack clash: 0.0 mm^3 into printed material
[PASS] stack inside cavity: 0.0 mm^3 of 32303 outside the fuselage
[PASS] vtx clash: 0.0 mm^3 into printed material
[PASS] vtx inside cavity: 0.0 mm^3 of 5400 outside the fuselage
[PASS] rx clash: 0.0 mm^3 into printed material
[PASS] rx inside cavity: 0.0 mm^3 of 660 outside the fuselage
[PASS] camera clash: 0.0 mm^3 into printed material
[PASS] camera inside cavity: 0.0 mm^3 of 7942 outside the fuselage
[PASS] motor 0 seats: 0.0 mm^3 clash
[PASS] motor 1 seats: 0.0 mm^3 clash
[PASS] motor 2 seats: 0.0 mm^3 clash
[PASS] motor 3 seats: 0.0 mm^3 clash

=== prop keep-out ===
[PASS] fuselage_lower vs props: 0.0 mm^3
[PASS] fuselage_upper vs props: 0.0 mm^3
[PASS] nose_cone vs props: 0.0 mm^3
[PASS] tail_cone vs props: 0.0 mm^3
[PASS] tail_fin vs props: 0.0 mm^3
[PASS] arm_top vs props: 0.0 mm^3
[PASS] arm_bottom vs props: 0.0 mm^3

=== printed part interference ===
[PASS] no part overlaps: worst arm_top / arm_bottom = 0.0 mm^3 (~0.00 mm over a saddle face)

=== each part is one solid ===
[PASS] fuselage_lower connected: 1 solid(s)
[PASS] fuselage_upper connected: 1 solid(s)
[PASS] nose_cone connected: 1 solid(s)
[PASS] tail_cone connected: 1 solid(s)
[PASS] tail_fin connected: 1 solid(s)
[PASS] arm_top connected: 1 solid(s)
[PASS] arm_bottom connected: 1 solid(s)

=== Neptune 4 bed (225 x 225 x 265) ===
[PASS] fuselage_lower x1: 190 x 62 x 48 mm, 64.4 g ea
[PASS] fuselage_upper x1: 190 x 57 x 18 mm, 28.5 g ea
[PASS] nose_cone x1: 47 x 55 x 55 mm, 13.2 g ea
[PASS] tail_cone x1: 49 x 50 x 50 mm, 13.4 g ea
[PASS] tail_fin x1: 28 x 20 x 51 mm, 6.8 g ea
[PASS] arm_top x1: 255 x 30 x 18 mm, 20.4 g ea  [print DIAGONALLY]
[PASS] arm_bottom x1: 255 x 30 x 18 mm, 21.5 g ea  [print DIAGONALLY]

=== mass ===
printed frame         168 g
  motors x4                        136 g
  stack                             34 g
  battery                          180 g
  camera                             8 g
  vtx + antenna                     16 g
  rx                                 2 g
  props x4                          18 g
  wiring, XT60, cap, heatshrink     25 g
  fasteners                         26 g
AUW                   613 g
static thrust        6400 g
[PASS] thrust-to-weight: 10.4:1

all checks passed

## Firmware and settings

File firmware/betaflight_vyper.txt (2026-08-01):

# =============================================================================
#  VYPER  --  Betaflight CLI configuration
#  4S / 2207 2450KV / 5x4.3x3 / F405 + 40A 4in1 / ExpressLRS
# =============================================================================
#
#  HOW TO USE
#    1. Flash Betaflight 4.5+ for your F405 target FIRST.
#    2. Betaflight Configurator -> CLI tab.
#    3. Paste this whole file, press Enter, then type: save
#    4. PROPS OFF for everything up to the final step.
#
#  Every non-default line below is here for a reason specific to THIS
#  airframe, and the reason is stated. Do not paste tuning you cannot explain.
# =============================================================================

# ---- Airframe ---------------------------------------------------------------
# True-X, 220 mm wheelbase, arms at 45/135/225/315. Standard quad X mixer;
# the 22 deg arm sweep is aerodynamic only and does NOT change the mix,
# because sweep moves the arm, not the thrust axis.
mixer QUADX

# PUSHER / INVERTED MOTORS.
# The motors bolt to the AFT face of the arms with the props behind them, so
# every motor turns the opposite way to a normal tractor quad. Reverse all
# four in BLHeli/AM32 (or with DShot beacon commands), then set this ON so
# Betaflight gets the yaw sign right. Get this wrong and the quad will flip
# on the yaw axis the instant you arm.
set yaw_motors_reversed = ON

# ---- ESC protocol -----------------------------------------------------------
# DSHOT600 is the right choice on a 4-in-1 with short traces. Bidirectional
# DShot gives us RPM telemetry, which is what makes RPM filtering possible --
# and RPM filtering is the single biggest tuning win available.
set motor_pwm_protocol = DSHOT600
set dshot_bidir = ON
set motor_poles = 14

# ---- Filtering --------------------------------------------------------------
# With RPM filtering on we can run the gyro lowpass much higher than stock,
# which cuts delay. The printed PETG airframe is LESS stiff than carbon, so
# its frame resonance sits lower -- the dynamic notch is left wide to catch it.
set gyro_lpf1_dyn_min_hz = 0
set gyro_lpf1_dyn_max_hz = 0
set gyro_lpf2_static_hz = 500
set dyn_notch_count = 3
set dyn_notch_q = 300
set dyn_notch_min_hz = 90
set dyn_notch_max_hz = 600
set dterm_lpf1_dyn_min_hz = 75
set dterm_lpf1_dyn_max_hz = 150
set dterm_lpf2_static_hz = 150

# ---- PID ---------------------------------------------------------------------
# Starting point only. The fuselage puts mass on the roll/pitch axes further
# from centre than a flat racer does, so P is backed off slightly from stock
# to avoid hot-motor oscillation on the first flight. Tune up from here.
set p_pitch = 45
set i_pitch = 80
set d_pitch = 38
set f_pitch = 120
set p_roll = 42
set i_roll = 76
set d_roll = 36
set f_roll = 115
set p_yaw = 45
set i_yaw = 80
set d_yaw = 0
set f_yaw = 120

# ---- Rates: smooth, for speed runs not freestyle ------------------------------
# Low centre sensitivity so small stick errors do not upset the airframe at
# 139 km/h, with full authority still available at the stick ends.
set rates_type = ACTUAL
set roll_rc_rate = 12
set pitch_rc_rate = 12
set yaw_rc_rate = 12
set roll_srate = 65
set pitch_srate = 65
set yaw_srate = 60
set roll_expo = 45
set pitch_expo = 45
set yaw_expo = 40

# ---- Receiver: ExpressLRS ------------------------------------------------------
set serialrx_provider = CRSF
set serialrx_inverted = OFF
# 250 Hz+ link: raise this to match your ELRS packet rate or you add latency.
set fpv_mix_degrees = 0

# ---- Battery: 4S 1500 ----------------------------------------------------------
set vbat_min_cell_voltage = 330
set vbat_warning_cell_voltage = 350
set vbat_max_cell_voltage = 435
set battery_capacity = 1500
# Calibrate this against a real charger reading after the first pack.
set ibata_scale = 400

# ---- Failsafe: DROP, not land ---------------------------------------------------
# A 567 g airframe doing 139 km/h that loses link must stop making thrust
# immediately. "Land" mode on a fast quad flies it a long way before it stops.
set failsafe_procedure = DROP
set failsafe_delay = 4
set failsafe_off_delay = 10

# ---- Arming safety ---------------------------------------------------------------
set small_angle = 180
set runaway_takeoff_prevention = ON
set gyro_cal_on_first_arm = OFF

# ---- Pusher-specific note -----------------------------------------------------
# Props ingest the body and arm wake in this layout, which shows up as
# blade-loading fluctuation -- broadband, not a clean tone. The dynamic notch
# above is set to 3 notches partly for that reason. If the blackbox shows a
# noise floor lift rather than a peak, that is the wake, not a balance problem,
# and chasing it with prop balancing will not help.

# ---- Motor output ------------------------------------------------------------------
set motor_output_limit = 100
# Idle set low: 5" on 4S has plenty of authority and a lower idle means less
# heat in a CLOSED FUSELAGE, which is this airframe's real thermal risk.
set dshot_idle_value = 450

# ---- OSD ----------------------------------------------------------------------------
set osd_vbat_pos = 2433
set osd_current_pos = 2465
set osd_craft_name_pos = 2081
set osd_rssi_dbm_pos = 2049
set name VYPER

save

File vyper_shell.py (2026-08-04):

"""
=============================================================================
 PEREGREEN-INSPIRED HIGH-SPEED ROCKET-DRONE FUSELAGE SHELL
 Parametric CadQuery model -- paste directly into CQ-Editor and press F5
=============================================================================

Inspired by the Peregreen V4 (Luke & Mike Bell, Cape Town), the fully
3D-printed quadcopter that set the Guinness record at 657.59 km/h in Dec 2025.
Two features of that aircraft drive this model:

  * the fuselage was printed as ONE seamless piece -- no joints to add weight,
    turbulence or a stress riser. This script produces a single closed solid
    for the same reason.
  * the outer contour was CFD-optimised (AirShaper) into a smooth, slightly
    fuller body. Here that is approximated analytically with a Von Karman
    ogive, which is the mathematically minimum-drag nose shape rather than a
    stylistic guess.

ORIENTATION
-----------
The model is built VERTICAL: +Z runs from the tail base (Z = 0) up to the nose
tip (Z = TOTAL_LEN). A tail-sitter rocket-drone stands on its base, so the
four arms leave the body horizontally and the props sweep in horizontal planes.

WHAT THIS IS AND IS NOT
-----------------------
This is the aerodynamic OUTER SHELL only. The arms are flat carbon plate that
you buy, cut and slide in through the slots from the inside; they are not
printed. The stack bolts to the internal shelf. Motors, battery, camera and
wiring are yours to place.

MATHEMATICAL SECTIONS (bottom to top)
-------------------------------------
  Z = 0 .. 60      BOAT-TAIL. Radius grows R_TAIL -> R_MAX on a cosine
                   easing. A boat-tail reduces base drag, which on a blunt
                   body is a large fraction of total drag.
  Z = 60 .. 170    PARALLEL MID-BODY at R_MAX. This is where the electronics,
                   the arm roots and the stack shelf live. Constant radius
                   because packaging, not aerodynamics, governs here.
  Z = 170 .. 300   VON KARMAN (LD-Haack) OGIVE. For a nose of given length and
                   base radius this minimises theoretical wave/pressure drag:

                       theta(x) = arccos(1 - 2x/L)
                       r(x)     = (R/sqrt(pi)) * sqrt(theta - sin(2*theta)/2)

                   with x measured aft from the tip. At x=0, r=0; at x=L, r=R.
                   Unlike a tangent ogive it meets the body with zero slope
                   discontinuity, so there is no shoulder to trip the flow.

The wall is a constant 2.0 mm, produced by revolving a second profile whose
radius is (outer - 2.0) and cutting it. A true `.shell()` operation is NOT
used: on a spline-revolved solid with this much curvature change OCC
frequently fails or produces non-uniform wall thickness. Two revolves and a
boolean is exact and always works.

=============================================================================
"""

import math

import cadquery as cq

# =============================================================================
# PARAMETERS -- everything is driven from here
# =============================================================================

# ---- Overall envelope -------------------------------------------------------
TOTAL_LEN = 300.0        # base (Z=0) to nose tip (Z=TOTAL_LEN)
# Set by the largest thing that must fit, which after the $150 re-spec is the
# 4S 1500 pack (75 x 35 x 30): half-diagonal 23.0 + 1.0 fit + 2.0 wall = 26.0.
# The old 60 mm body was sized by a 44 mm-wide SpeedyBee ESC; the budget
# 36 x 36 stack does not need it, so the aircraft got 25% less frontal area.
R_MAX = 26.0             # max outer radius -> 52 mm diameter body
WALL = 2.0               # constant shell wall thickness

# ---- Longitudinal stations --------------------------------------------------
Z_TAIL_TOP = 60.0        # boat-tail ends / parallel body begins
Z_NOSE_BASE = 170.0      # parallel body ends / ogive begins
R_TAIL_BASE = 21.0       # radius at the very base (Z=0)
R_TIP = 0.6              # tiny flat at the tip: a knife point will not print

# ---- Arm slots --------------------------------------------------------------
# Flat carbon plate arms slide in from the INSIDE and out through the wall.
ARM_COUNT = 4
ARM_ANGLES = [45.0, 135.0, 225.0, 315.0]   # true-X quadcopter
# The blade stands ON EDGE: 26 mm tall, 6 mm thick streamwise. Motor thrust
# is vertical, so depth in Z is what resists bending -- a 6 mm-thick flat
# plate lying horizontally would be 18x less stiff for the same material.
# It is also the low-drag orientation, since 6 mm is what the air sees.
ARM_THICK = 6.0          # streamwise thickness (horizontal)
ARM_WIDTH = 26.0         # vertical depth -- carries the bending
ARM_FIT = 0.4            # total slip fit added to BOTH slot dimensions
ARM_Z = 95.0             # slot centre height -- lower-middle of the body
ARM_REACH = 60.0         # how far the cutter runs past R_MAX

# ---- Internal flight-stack shelf -------------------------------------------
SHELF_Z = 135.0          # top face of the shelf
SHELF_T = 3.0            # shelf thickness
STACK_PITCH = 30.5       # standard 30.5 x 30.5 mounting pattern
STACK_HOLE_D = 3.2       # M3 clearance in printed PETG (see note below)
SHELF_VENT_D = 18.0      # central pass-through for the ESC / motor looms

# ---- Cavity extent ----------------------------------------------------------
CAVITY_BOTTOM = -1.0     # below Z=0, so the base is OPEN for assembly
MIN_INNER_R = 2.5        # stop hollowing once the nose gets this thin

PROFILE_STEPS = 60       # spline sample count per curved section

# ---- Print split ------------------------------------------------------------
# The 300 mm body is printed standing, which is the only sensible orientation
# for a body of revolution. It does not fit a 265 mm-Z bed: at the 95 % usable
# height that is 251.75 mm, so the part is 48 mm too tall.
#
# Printing it as one piece was the stated intent, following the Peregreen V4.
# That is worth keeping where it is affordable and it is not affordable here,
# so the question becomes WHERE to split rather than whether to.
#
# Z = 170 is the answer, for three reasons that all point the same way:
#   * it is the ogive/parallel-body junction, which the Von Karman profile
#     already meets with zero slope discontinuity. A joint there adds no
#     shoulder the flow was not already seeing.
#   * both halves then print standing: 170 mm body and 130 mm nose, against
#     251.75 mm usable. Neither needs support it did not already need.
#   * the arms land at Z = 95 and the shelf at Z = 135, both well below the
#     joint, so the split is entirely outside the loaded region. The nose
#     carries nothing but its own air load.
#
# The joint is a LAP, not a butt: each half keeps half the wall through the
# overlap, so glue area is the full 25 mm of engagement rather than a 2 mm
# end-grain ring. A butt joint here would be the stress riser the one-piece
# argument was trying to avoid.
SPLIT_ENABLE = True
SPLIT_Z = 170.0          # ogive base -- see above
SPIGOT_L = 25.0          # lap engagement length
SPIGOT_FIT = 0.25        # radial clearance, nose spigot into body socket


# =============================================================================
# PROFILE MATHEMATICS
# =============================================================================

def von_karman_radius(x, length, base_radius):
    """Von Karman (LD-Haack) ogive radius at distance x aft of the tip.

        theta = arccos(1 - 2x/L)
        r     = (R / sqrt(pi)) * sqrt(theta - sin(2*theta)/2)

    This is the minimum-drag body of revolution for a given length and base
    diameter under Sears-Haack theory. It is the reason the nose here is not
    simply a cone or a circular-arc ogive.
    """
    x = min(max(x, 0.0), length)                 # clamp against float drift
    theta = math.acos(1.0 - 2.0 * x / length)
    return (base_radius / math.sqrt(math.pi)) * math.sqrt(
        theta - math.sin(2.0 * theta) / 2.0
    )


def boat_tail_radius(z):
    """Cosine easing from R_TAIL_BASE at Z=0 to R_MAX at Z_TAIL_TOP.

    A cosine (rather than a straight taper) gives zero slope at both ends, so
    the tail blends into the parallel body with no visible crease and no
    separation-triggering corner.
    """
    t = z / Z_TAIL_TOP
    return R_TAIL_BASE + (R_MAX - R_TAIL_BASE) * (1.0 - math.cos(math.pi * t)) / 2.0


def outer_profile():
    """Full outer half-profile as a list of (radius, z), base -> tip."""
    pts = []

    # --- 1. Boat-tail: Z = 0 .. Z_TAIL_TOP
    for i in range(PROFILE_STEPS + 1):
        z = Z_TAIL_TOP * i / PROFILE_STEPS
        pts.append((boat_tail_radius(z), z))

    # --- 2. Parallel mid-body: Z_TAIL_TOP .. Z_NOSE_BASE
    # Sampled rather than a single endpoint. A spline given two identical
    # radii far apart will bow between them; a dense polyline cannot.
    for i in range(1, 21):
        pts.append((R_MAX, Z_TAIL_TOP + (Z_NOSE_BASE - Z_TAIL_TOP) * i / 20.0))

    # --- 3. Von Karman ogive: Z_NOSE_BASE .. TOTAL_LEN
    nose_len = TOTAL_LEN - Z_NOSE_BASE
    for i in range(1, PROFILE_STEPS + 1):
        # x is measured AFT FROM THE TIP, so walk it backwards to go up in Z
        x = nose_len * (PROFILE_STEPS - i) / PROFILE_STEPS
        r = von_karman_radius(x, nose_len, R_MAX)
        z = TOTAL_LEN - x
        pts.append((max(r, R_TIP), z))

    return pts


def inner_profile(outer_pts):
    """Offset the outer profile inward by WALL to form the cavity.

    Truncated once the wall would consume the section (near the tip), which
    leaves the nose solid -- convenient, because that is where you want mass
    for CG anyway on a tail-sitter.
    """
    pts = [(max(outer_pts[0][0] - WALL, MIN_INNER_R), CAVITY_BOTTOM)]
    for r, z in outer_pts:
        r_in = r - WALL
        if r_in < MIN_INNER_R:
            break
        pts.append((r_in, z))
    return pts


# =============================================================================
# SOLID CONSTRUCTION
# =============================================================================

def revolve_profile(pts, close_top=True):
    """Revolve a (radius, z) half-profile about the Z axis.

    NOTE ON THE WORKPLANE: on Workplane("XZ") the local axes map to global
    (X, Z), so a local point (r, z) sits at global (r, 0, z). The revolve axis
    is therefore the LOCAL y axis -- (0,0) to (0,1) -- not the global Z tuple.
    Getting this wrong is the classic CadQuery revolve mistake.
    """
    z_bottom = pts[0][1]
    z_top = pts[-1][1]

    # POLYLINE, not spline. A spline fitted through the whole profile
    # overshoots at the two slope discontinuities (boat-tail -> parallel body,
    # body -> ogive), self-intersects, and the revolve then yields a negative
    # volume made of a dozen fragments. At 60 samples per curved section the
    # facets are far below layer resolution, so nothing is lost.
    chain = [(0.0, z_bottom), (pts[0][0], z_bottom)]
    chain += [(r, z) for r, z in pts[1:]]
    if close_top:
        chain.append((0.0, z_top))

    return (
        cq.Workplane("XZ")
        .polyline(chain)
        .close()
        .revolve(360.0, (0, 0), (0, 1))
    )


def build_shell():
    # ---- 1. Outer aerodynamic body ------------------------------------------
    outer_pts = outer_profile()
    body = revolve_profile(outer_pts)

    # ---- 2. Hollow it to a constant 2 mm wall --------------------------------
    cavity = revolve_profile(inner_profile(outer_pts))
    shell = body.cut(cavity)

    # ---- 3. Internal flight-stack shelf --------------------------------------
    # Radius deliberately exceeds the local inner radius so the disc merges
    # INTO the wall rather than sitting tangent to it -- a tangent disc unions
    # as a separate floating solid.
    shelf_r = R_MAX - WALL + 0.5
    shelf = (
        cq.Workplane("XY")
        .workplane(offset=SHELF_Z - SHELF_T)
        .circle(shelf_r)
        .extrude(SHELF_T)
    )
    shell = shell.union(shelf)

    # ---- 3a. Self-supporting ramp under the shelf ----------------------------
    # The shelf is an annular ledge reaching 15.5 mm inward from the wall with
    # nothing beneath it: a 90 deg overhang of about 1520 mm^2. That is the
    # single largest overhang on the airframe, and unlike an external one it
    # cannot be solved with support material -- this face is 132 mm up a 48 mm
    # bore, so any support printed under it stays there forever.
    #
    # The fix is a cone under the shelf running back down to the wall at 45
    # deg. Each layer then steps inward by exactly its own height, which is the
    # self-support limit, so it prints unsupported and the ledge lands on solid
    # material. It also fillets the shelf-to-wall joint, which is where a
    # cantilevered ledge would otherwise crack first.
    #
    # Cost is 15.5 mm off the top of the battery bay, leaving about 116 mm of
    # clear cavity for a 75 mm pack. If that ever gets tight, widening
    # SHELF_VENT_D shortens the ramp one-for-one.
    # Built as a conical SHELL, not a solid cone. Only the surface has to be
    # there -- the shelf needs something to land on, not a plug. A solid cone
    # costs about 20 g, which on a 600 g airframe is 3 % of all-up weight
    # bought for nothing.
    ramp_h = shelf_r - SHELF_VENT_D / 2.0
    ramp_z0 = SHELF_Z - SHELF_T - ramp_h
    ramp_wall = WALL * math.sqrt(2.0)      # 45 deg cone: vertical offset for
    #                                        a WALL-thick normal section
    ramp = (
        cq.Workplane("XY").workplane(offset=ramp_z0)
        .circle(shelf_r).extrude(ramp_h)
    ).cut(
        cq.Workplane("XY").workplane(offset=ramp_z0)
        .circle(shelf_r)
        .workplane(offset=ramp_h)
        .circle(SHELF_VENT_D / 2.0)
        .loft()
    ).cut(
        cq.Workplane("XY").workplane(offset=ramp_z0)
        .circle(shelf_r + ramp_wall)
        .workplane(offset=ramp_h)
        .circle(SHELF_VENT_D / 2.0 + ramp_wall)
        .loft()
    )
    shell = shell.union(ramp)

    # 30.5 x 30.5 stack pattern + a central loom pass-through.
    #
    # Cut with explicit cylinders rather than .faces(">Z").hole(): on a body
    # of revolution the ">Z" selector resolves to the nose tip (or to nothing
    # at all after a boolean), not to the shelf you just added. Positioning
    # the cutters absolutely is unambiguous and cannot mis-select.
    half = STACK_PITCH / 2.0
    for sx in (-half, half):
        for sy in (-half, half):
            bolt = (
                cq.Workplane("XY")
                .workplane(offset=SHELF_Z - SHELF_T - 2.0)
                .center(sx, sy)
                .circle(STACK_HOLE_D / 2.0)
                .extrude(SHELF_T + 4.0)
            )
            shell = shell.cut(bolt)

    vent = (
        cq.Workplane("XY")
        .workplane(offset=SHELF_Z - SHELF_T - 2.0)
        .circle(SHELF_VENT_D / 2.0)
        .extrude(SHELF_T + 4.0)
    )
    shell = shell.cut(vent)

    # ---- 4. Arm slots --------------------------------------------------------
    # Each cutter starts on the axis and runs radially outward, so the slot is
    # open to the cavity: the carbon plate feeds in from inside and pushes out.
    slot_w = ARM_WIDTH + ARM_FIT      # vertical
    slot_t = ARM_THICK + ARM_FIT      # streamwise
    cut_len = R_MAX + ARM_REACH

    for angle in ARM_ANGLES:
        cutter = (
            cq.Workplane("XY")
            .box(cut_len, slot_t, slot_w)
            .translate((cut_len / 2.0, 0, ARM_Z))
            .rotate((0, 0, 0), (0, 0, 1), angle)
        )
        shell = shell.cut(cutter)

    return shell


# =============================================================================
# ARM  --  four identical blades, slid in through the slots from inside
# =============================================================================

R_MOTOR = 110.0          # motor centre radius -> 220 mm true-X wheelbase
HUB_CORE_R = 10.0        # solid core the four hub slots stop short of
ARM_ROOT_R = 11.0        # arm root radius -- four arms cannot all cross centre
ARM_TIP_OVER = 15.0      # blade reach past the motor centre
MOTOR_PATTERN = 16.0     # 2207-class M3 square
MOTOR_PAD_T = 4.0        # left under the motor -> M3x8 and nothing longer
MOTOR_BORE_D = 9.0       # bell boss relief

# ---- Print orientation ------------------------------------------------------
# MEASURED, not assumed. The blade underside sits 22 deg off horizontal (it is
# the swept face), which is a 68 deg overhang if the arm is sliced as modelled.
# Rotating the part about Y by more than ARM_SWEEP steepens that whole face
# past the 45 deg self-support limit. Facet-level sweep of the exported STEP:
#
#     rotation      overhang area     worst
#      0 deg        1182 mm^2          68 deg     <- as modelled, needs support
#     25 deg         510 mm^2          65 deg     <- best
#     45 deg         464 mm^2          76 deg     but on a cliff edge: 45.5 deg
#                                                 flips a large face and it
#                                                 jumps back to 2114 mm^2
#
# 25 deg is the setting to use: over half the overhang area gone for free, and
# it sits in the middle of a stable window rather than on the edge of one.
#
# NOTE: an earlier version of this docstring claimed the arm printed
# "top-face-down with nothing needing support". That is false and was never
# measured - top-face-down is a 158 deg rotation and scores 1957 mm^2, the
# WORST of any orientation tried.
PRINT_ROT_Y = 25.0       # degrees about Y for the print-oriented export

# ---- Arm sweep --------------------------------------------------------------
# On a tail-sitter, "angled down" means swept AFT, because at speed the body
# axis IS the flight direction. That is worth doing: a strut swept by Lambda
# sees only the crossflow component, so its profile drag falls roughly as
# cos^2(Lambda).
#
#   0 deg  -> cos^2 = 1.00   (baseline)
#   20 deg -> cos^2 = 0.88   (-12 % arm drag)
#   30 deg -> cos^2 = 0.75   (-25 % arm drag)
#
# What is NOT done here is canting the MOTORS. The pad stays normal to the
# body axis, so thrust stays on the flight axis and there is no cos(theta)
# thrust loss. Tilting the motors themselves would cost 3.4 % of thrust at
# 15 deg and buy nothing on a tail-sitter -- the body already aligns.
ARM_SWEEP = 22.0         # degrees aft ("down" when standing on the tail)

# ---- PUSHER configuration ---------------------------------------------------
# Motors mount on the AFT face of the arm, props behind them, pushing.
#
# Why pusher and not tractor, for a speed airframe specifically:
#
#   TRACTOR (props at the nose end) gives the prop clean inflow, but its
#   slipstream then washes the ENTIRE fuselage at well above freestream
#   velocity. Skin-friction drag scales with local dynamic pressure, so you
#   pay for that over the whole wetted area -- and this body is nearly all
#   the wetted area there is.
#
#   PUSHER costs the prop some inflow quality (it ingests body and arm wake,
#   which shows up as blade-loading fluctuation and noise) but leaves the
#   fuselage in clean, undisturbed air.
#
# On a body this slender with this much wetted area relative to disc area,
# keeping the fuselage out of the slipstream is the larger effect. It is also
# why high-speed UAVs are overwhelmingly pushers.
#
# Practical consequence: the motors are mounted INVERTED. Same props, but
# motor direction must be reversed in Betaflight -- see firmware/.
PUSHER = True
HUB_BOLT_D = 3.2
WIRE_BORE_D = 6.0        # 3x 20 AWG silicone, hand-pullable
# Boat-tail behind the motor pad. Two numbers, and both are set by print
# overhang as much as by drag:
#   * the cone FLANK is an overhang equal to its own half-angle, and the print
#     rotation above adds to it. atan((1-PAD_TAIL_R)*pad_r / PAD_TAIL_L) must
#     stay under (45 - PRINT_ROT_Y) = 20 deg or the flank needs support.
#   * the flat aft END is a 90 deg face. Shrinking PAD_TAIL_R shrinks it, and
#     also removes base area, which is what the boat-tail is for.
# 0.45 over 14 mm gave a 31 deg flank and a 149 mm^2 flat. 0.35 over 24 mm
# gives a 19.5 deg flank -- self-supporting at 25 deg print rotation -- and
# drops the flat to 90 mm^2.
PAD_TAIL_L = 24.0        # boat-tail length below the pad
PAD_TAIL_R = 0.35        # aft radius as a fraction of pad radius
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

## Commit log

2026-07-30 VYPER-5: 5in 6S printed racing quad, full CAD + verified BOM
    Six-part airframe, all STL, no supports, printed on a Neptune 4.
    Design is driven by print orientation: the arm's motor pad face is the bed
    face, all taper is on the underside so cross-section only shrinks going up,
    and peak bending fibres land as continuous full-length perimeters.
    76 g printed frame, ~543 g AUW, ~11.8:1 thrust-to-weight.
    verify.py checks prop keep-out by boolean intersection, part-to-part overlap,
    camera sightline vs the battery nose, and Neptune 4 bed fit. It caught an
    0.8 mm stack-up error, a camera cage colliding with the front arms, and an
    antenna blade clipping the top plate.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
    [antenna_mount.step, antenna_mount.stl, arm.step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]
2026-07-30 VYPER-5F: redesign to a faired fuselage airframe, cut to the real parts
    Replaces the flat-plate airframe with a streamlined body-of-revolution
    fuselage, battery and stack buried inside, four swept faired pylons ending in
    motor nacelles.
    Fit is carved, not drawn: components.py models every bought part at its
    spec-sheet size and the bays are booleaned out of the structure using those
    solids. The SpeedyBee ESC at 45.6x44 mm is what sets the 62 mm fuselage
    diameter.
    Print orientation still drives the geometry. The pylon is flat-topped over its
    whole length so that face is both bed face and motor mounting face, which is
    why the pylons leave the fuselage at the shoulder rather than the waterline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
    [antenna_mount.step, antenna_mount.stl, arm.step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]
2026-07-30 Rewrite build guide for the faired airframe
    Assembly section still described the plate frame's arms, standoffs and battery
    strap, none of which exist now.
2026-07-30 Fix tail fin proportions and add showcase renders
    Fin foot ran past the tail tip and hung in free air; it was also wider than
    the local tail diameter so it overhung instead of wrapping. Moved forward,
    shortened, narrowed, and the blade raised so it reads as a fin rather than a
    pedestal.
    Adds assembly_view.py -- same geometry without the 127 mm prop keep-out discs,
    which cover most of the aircraft in a render.
    [tail_cone.step, tail_cone.stl, tail_fin.step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]
2026-07-31 VYPER-5W: rocket airframe with swept wings, plus aero and tolerance testing
    Redesigned to the Peregreen V4 layout the user asked for: the motors are no
    longer on arms poking sideways, they sit ON two swept arrowhead wing panels
    drawn around them, on a rocket fuselage. Motor stations moved to an explicit
    stretched-X table (+-70, +-72) since a 45-degree true X does not fit inside a
    swept planform with 127 mm props.
    Wing panels are hollowed from below -- free to print when the panel goes
    top-face-down -- with skin, perimeter, six ribs and a lightening bay, taking
    each panel from 92 g solid to 31 g.
    New testing:
    aero.py component drag build-up, lift, prop-pitch speed limit,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
    [fuselage_lower.step, fuselage_lower.stl, fuselage_upper.step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]
2026-07-31 Update README for the wing airframe
2026-07-31 Fix frame geometry to a real stretched X
    The layout was 140 x 144 mm -- square, so a true X in name only, getting the
    benefit of neither. Now 176 mm fore-aft against 140 mm lateral, a 1.26:1
    stretch, with lateral spacing pinned at the 127 mm prop minimum.
    Two reasons this is the right geometry for a speed airframe: it is narrower,
    and frontal area is what you pay for at speed; and it pulls the rear discs out
    of the front discs' wake instead of leaving them 140 mm astern in disturbed
    air.
    The stretch ratio is capped by the Neptune 4 bed, not by aero -- the wing has
    to reach 15 mm past each motor pad, so 2*88+34 = 210 mm is the longest panel
    that still fits. Added checks so the ratio and the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
    [fuselage_lower.step, fuselage_lower.stl, fuselage_upper.step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]
2026-07-31 VYPER-5X: two crossed blade arms with a faired body, replacing the wings
    The swept wing panels were the wrong trade for a speed airframe -- they made
    lift but they made frontal area and rotor download too. This is the crossed
    chopstick layout: two straight 9 x 18 mm blades half-lapped at the centre,
    motors at the four ends, streamlined body along the spine.
    A 9 mm blade edge-on presents almost nothing, so the remaining drag is the
    body (faired) and the motors. Frame mass drops from 261 g to 168 g and T/W
    rises to 10.4:1.
    Arms are 255 mm and do NOT fit a 225 mm bed square; they go on diagonally,
    needing 201 mm. verify.py now tests rotated bed fit rather than failing them.
    KNOWN COMPROMISE: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
    [arm_bottom.step, arm_bottom.stl, arm_top.step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]
2026-07-31 Rewrite aero analysis for the crossed-blade airframe
    aero.py still measured wing planform, wing lift and wing rotor download after
    the wings were removed -- it ran clean and reported numbers for an aircraft
    that no longer existed, which is worse than failing.
    Now measures the blade silhouette and blade area inside the discs. Results:
    blades are 18% of drag against the wings' 13%, but rotor download falls from
    2.2% to 0.5% of thrust and the frame is 93 g lighter. Motors remain the
    dominant drag item at 74%.
2026-07-31 Update build and BOM docs for the crossed-blade airframe
    Assembly steps still described pylon flanges, wing roots and a battery strap,
    none of which exist. Rewritten for the interlocking arms, and the printing
    section now states the 45-degree bed rotation the 255 mm arms require.
2026-07-31 Add Peregreen-inspired rocket fuselage shell as a standalone CadQuery script
    Vertical tail-sitter shell: Von Karman (LD-Haack) minimum-drag ogive nose,
    parallel mid-body, cosine boat-tail, 2 mm constant wall, four radial slots for
    flat carbon arms fed in from inside, and an internal 30.5 x 30.5 stack shelf.
    Verified by execution, not just written: 60 x 60 x 300 mm, 95,061 mm^3, ONE
    closed solid.
    Two bugs found and fixed by running it:
    - .faces('>Z[-1]').hole() resolves to the nose tip on a body of revolution,
    not the shelf just added; replaced with absolutely-positioned cutters.
    - a spline fitted through the whole profile overshoots at the two slope
    discontinuities, self-inters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
    [peregreen_shell.step, peregreen_shell.stl]
2026-07-31 Complete Peregreen-X drone: arms, hub, $150 BOM, full test suite
    Adds the four X arms and the internal hub, so this is a complete airframe
    rather than a bare shell. Arms are vertical blades (6 mm streamwise x 26 mm
    deep) rather than flat plate: thrust is vertical, so depth in Z is what
    resists bending, and 6 mm is what the air sees.
    Re-specced to under $150 ($142). The interesting consequence is that the
    cheaper parts are SMALLER -- a 36x36 budget stack and a 75x35x30 4S pack
    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
    [peregreen_arm.step, peregreen_arm.stl, peregreen_hub.step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]
2026-07-31 Sweep the arms aft 22 deg, boat-tail the motor nacelles, fix arm drag error
    Sweep: on a tail-sitter the body axis IS the flight direction at speed, so
    'angled down' means swept aft, and a swept strut only sees the crossflow
    component -- profile drag falls as cos^2(sweep), 0.86 at 22 deg. The motor pad
    stays NORMAL to the body axis, so thrust is not canted and there is no
    cos(theta) thrust loss. Canting the motors themselves would cost 3.4% of
    thrust at 15 deg and buy nothing here.
    Nacelle: the pad's axis lies along the flow, so it behaves as a nacelle and
    its drag is base drag off the flat aft end. Boat-tailed to 45% radius. A plan
    teardrop was tried first and was simply on the wrong axis.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
    [peregreen_arm.step, peregreen_arm.stl, pg_assembly.step]
2026-07-31 Correct motor screw spec: thread depth was wrong
    I had the 2207 blind thread at 3.0 mm and warned the user off M3x8 toward
    M3x6. That was wrong. 2207-class motors are built for 4-5 mm carbon arms and
    ship M3x8 for exactly this stack-up; their blind holes are 4.5-5.0 mm. A 4.0
    mm pad with M3x8 gives 4.0 mm engagement with 0.5 mm spare -- the standard,
    correct combination. M3x6 would have left only 2 mm and been the worse choice.
    Adds three checks so the stack-up is enforced rather than asserted: screw
    engagement against real thread depth, head bearing stress on PETG (0.18 MPa --
    fine, but washers are still specified because vibration embeds a bare head),
    and material remaining outboard of ea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
2026-07-31 Prepare Peregreen-X for public release
    Adds Betaflight firmware config with every non-default value justified, a
    bench/pre-flight procedure including the mandatory thermal check for a sealed
    fuselage, BOM links, MIT licence, LinkedIn write-up, and a README that states
    plainly this is a verified design and not a flown aircraft.
    [betaflight_peregreen_x.txt]
2026-07-31 Move earlier iterations to legacy/, keep only Peregreen-X parts at root
    The repo carried STLs and CAD from four superseded layouts alongside the
    current CadQuery design, which is confusing for anyone arriving from the
    README. Moved to legacy/ with a note on what they were and why they are kept.
    [arm_bottom.step, arm_top.step, assembly.step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]
2026-07-31 Remove superseded STLs from stl/
    [arm_bottom.stl, arm_top.stl, fuselage_lower.stl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]
2026-07-31 Rename project to VYPER
    Repo, files, firmware config and docs all renamed. The Peregreen V4 keeps its
    own name wherever it appears -- it is credited as the inspiration, and it is
    someone else's record-holding aircraft, not this one.
    [betaflight_vyper.txt, vyper_arm.step, vyper_arm.stl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]
2026-08-01 Convert to pusher configuration and add wire routing
    PROPS NOW POINT AFT. Motors bolt to the aft face of the arms, props behind
    them. Reasoning: a tractor gives the prop clean inflow but washes the entire
    fuselage in slipstream above freestream velocity, and skin friction scales
    with local dynamic pressure over what is nearly all the wetted area on this
    airframe. A pusher costs the prop some inflow quality -- it ingests body and
    arm wake -- and keeps the body in clean air. On a slender body with this much
    wetted area relative to disc area that is the larger effect, and it is why
    high-speed UAVs are overwhelmingly pushers.
    WIRE ROUTING: 6 mm bore down each blade from the motor pocket to the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
    [betaflight_vyper.txt, vyper_arm.step, vyper_arm.stl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]
2026-08-01 VYPER-F4: custom flight controller PCB, dimensioned and interaction-checked
    KiCad 9 board generated from a single Python layout module (pcbnew's Save()
    segfaults headless on macOS, so the file is emitted as s-expressions directly
    and kicad-cli render doubles as the format validator).
    36x36 / 30.5x30.5, Phi4 grommet holes, ICM-42688-P at (0,+2.5), F405 SPI run
    under 10 mm, buck inductor 10.7 mm from the gyro, USB + 8-pin ESC socket on
    the bottom face because the airframe dictates both.
    test_vyper_f4.py: 15 checks -- pattern, hole-edge web, corner-radius-vs-
    fuselage (a square 36x36 board does NOT fit the 48 mm cavity), shelf vent,
    gyro rules, courtyard pairs, pads vs courtyards, grommet kee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
    [vyper_f4.kicad_pcb]
2026-08-04 Split the shell to fit the bed; fix arm and shelf overhangs
    BED FIT. The 300 mm body printed standing needs 251.75 mm of usable Z
    on a 265 mm bed. It was 48 mm too tall and had never been checked.
    Split at Z = 170, which is the best available station for three
    reasons: it is the ogive/parallel-body junction the Von Karman
    profile already meets with zero slope discontinuity, both halves then
    print standing (170 and 155 mm), and it sits above the arms at Z = 95
    and the shelf at Z = 135 so the joint carries no structural load.
    The joint is a lap, not a butt: each half keeps half the 2 mm wall
    through 25 mm of overlap, so the bond is 25 mm of shear area instead
    of a 2 mm end-grain ring. One-pie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
    [vyper_arm_print.step, vyper_shell_body.step, vyper_shell_nose.step]
2026-08-04 Regenerate STLs for the split shell and revised arm
    The stl/ directory still held the one-piece 300 mm shell, which does
    not fit a 265 mm bed and was superseded by the Z=170 split. Anyone
    printing from stl/ would have gone straight into a failed print.
    Renamed rather than deleted, with the reason in the filename.
    [vyper_arm.stl, vyper_arm_print.stl, vyper_shell_body.stl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]
